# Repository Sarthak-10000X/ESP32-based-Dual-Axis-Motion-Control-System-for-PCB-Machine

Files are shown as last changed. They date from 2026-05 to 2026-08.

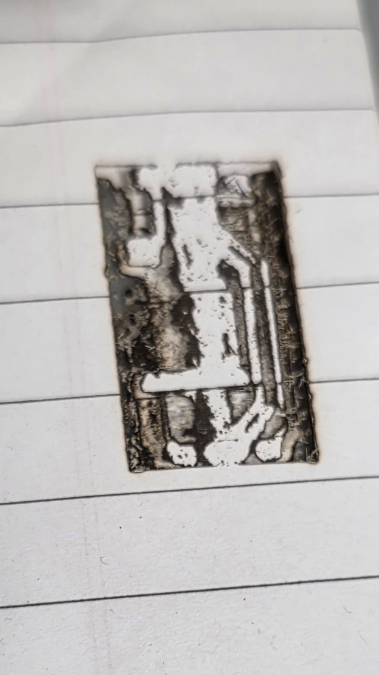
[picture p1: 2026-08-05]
Images-Prototyping/paper trial to test calibration.jpeg

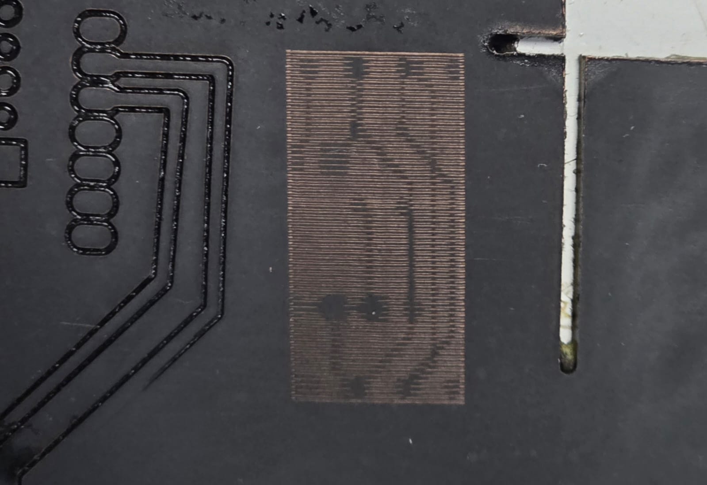
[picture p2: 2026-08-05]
Images-Prototyping/Changed grayscale. Issue remains.jpeg

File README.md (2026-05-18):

# ESP32-based-Dual-Axis-Motion-Control-System-for-PCB-Machine
This project implements a dual-axis motion control system for a PCB machine using the ESP32 microcontroller and TMC2209 stepper motor drivers. It is designed to deliver smooth, precise and low-noise motion through advanced micro-stepping making it suitable for PCB plotting or light CNC applications.

I have choosen the TMC2209 Stepper motor driver because it provides smooth and silent operations using microstepping. It is a 2 phase stepper motor upto 2.8A peak current, 2A RMS. STEP/DIR Interface with 8,16,32 or 64 microstep pin setting. StealthMode2 that is Silent Motor Operation and Smooth Running 256 Microsteps by MicroPlayer interpolation. Additionally, it's UART Interface allows advanced control and tuning making it more suitable for traditional stepper drivers like A4988 or DRV8825.

Heat dissipation is handled using heatsink on the TMC2209 drivers. Each TMC2209 can be equipped with a small aluminum heatsink to dissipate heat generated during operation. Motor current can be properly set via UART to prevent overheating at the source. Use of large copper area helps to spread heat away from the driver.
Power routing is designed with seperate motor, where a 24V supplies the motor drivers and a buck converter provides 5V for the ESP32 and logic pins. Bulk Capacitor are placed across Vm and GND to absorb volatge spikes, while ceramic capacitors ensure stable and high frequency logic voltage. Common grounding used to ensure system stability.

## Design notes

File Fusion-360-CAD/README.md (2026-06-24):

# CAD Practice Models

## Overview

This directory contains CAD models created as part of the learning and skill-development process in Fusion 360. The purpose of these models was to gain hands-on experience with sketching, extrusion, revolves, assemblies, and basic mechanical design principles.

## Software Used

- Fusion 360

## Learning Outcomes

Through the development of these models, the following skills were practiced:

- 2D sketching and dimensioning
- 3D feature creation
- Component-based design
- Assembly fundamentals
- CAD workflow and model organization

## Future Improvements

- Create more complex mechanical assemblies
- Perform motion and interference analysis
- Design project-specific components for the PCB prototyping machine
- Improve design documentation and manufacturing readiness
  
These models were developed for educational and skill-development purposes as part of the PCB Prototyping Machine project.

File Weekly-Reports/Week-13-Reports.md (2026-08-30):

## Week 13 Progress Report: Custom CNC Control Board Development

# Overview:

-Focused on developing the custom control board for the CNC machine.
-Reviewed and updated the circuit schematic based on the required voltage levels, components, protection, and control interfaces.
-Finalized the initial Bill of Materials (BOM) and component footprints for PCB design.

# Tasks Completed:

-Prepared the Bill of Materials (BOM) for the custom CNC control board.
-Assigned appropriate PCB footprints to the selected components.
-Reviewed the power architecture, including 12V input and 5V regulation.
-Evaluated components such as the ATmega328P, LM358, AMS1117, TMC2209, MOSFETs, TVS/flyback protection, and connectors.
-Planned I²C header pins, ISP connector, serial interface, limit-switch connections, and control outputs.
-Added provisions for microstepping selection and future hardware flexibility.
-Reviewed protection requirements for the pump and other inductive loads, including flyback diode and fuse connections.

# Challenges Faced:

-Finalizing the correct components and footprints for reliable PCB implementation.
-Verifying the ATmega328P pin assignments and additional GPIO requirements.
-Determining suitable PWM/control pins for the laser, pump, servo, and safety functions.
-Ensuring adequate protection against voltage spikes, current overload, and inductive switching.

# Key Outcomes:

-Established the initial custom CNC control-board architecture.
-Completed the BOM and PCB footprint assignment for the selected components.
-Identified key hardware requirements for motor control, laser control, pump operation, safety interlocks, and sensors.
-Improved the schematic based on the requirements identified during prototype testing.
-Prepared the design for the next stage of PCB layout and hardware implementation.

# Next Steps:

-Finalize and verify the complete schematic and component selection.

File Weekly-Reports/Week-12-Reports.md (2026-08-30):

# Week 12 Progress Report: Prototype Completion & System Integration

## Overview

- Focused on completing the first functional CNC prototype by integrating the servo-based etching mechanism with the existing CNC system.
- Explored multiple hardware and firmware approaches for controlling the servo motor.
- Successfully integrated and tested the laser, pump, and servo system to validate the complete CNC operation.

## Tasks Completed

- Tested multiple servo-control and wiring configurations.
- Investigated LaserGRBL/GRBL firmware modifications for additional PWM-based control.
- Integrated the etching pump and servo mechanism with the CNC system.
- Performed complete system testing to verify coordinated operation of the major CNC components.

## Challenges Faced

- Difficulty identifying a suitable PWM-capable output for direct servo control within the existing CNC controller configuration.
- Required evaluation of multiple hardware components and circuit configurations to achieve reliable operation.
- Existing Arduino UNO + CNC Shield V3 architecture provided limited outputs for additional peripherals.

## Key Outcomes

- Successfully completed the first functional CNC prototype.
- Verified the operation of the laser, stepper motors, pump, and servo mechanism.
- Tested and evaluated multiple hardware and firmware approaches for peripheral control.
- Established a working prototype that can serve as the foundation for the next-generation CNC control board.

## Next Steps

- Design and develop a custom CNC control PCB integrating the required motion, laser, pump, and servo-control circuitry.
- Study the STM32 microcontroller platform for improved PWM, GPIO, motion-control, and peripheral capabilities.
- Evaluate STM32 as a potential replacement for the Arduino UNO-based control architecture.
- Begin planning the circuit architecture and pin mapping for the custom CNC controller.

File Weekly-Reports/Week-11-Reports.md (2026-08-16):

## Week 11 Progress Report: Firmware Evaluation & PWM Signal Analysis

# Overview

- Focused on evaluating and modifying the LaserGRBL control system to support an additional PWM-controlled output.
- Investigated available PWM signals on the Arduino UNO with CNC Shield V3 using an oscilloscope.
- Tested different spray-paint coatings to determine their suitability for laser engraving PCB traces.
- Troubleshot and resolved a low-laser-power issue observed during engraving.

# Tasks Completed

- Checked PWM outputs from different pins available on the CNC Shield V3.
- Used an oscilloscope to verify PWM signal generation and behavior.
- Investigated the possibility of assigning an additional PWM output for pump-speed control.
- Resolved the previously observed low laser-power problem and verified improved laser operation.
- Tested engraving quality and examined the resulting trace patterns.
- Evaluated different spray-paint coatings for improved laser engraving performance.

# Challenges Faced

- No suitable additional PWM output was identified apart from the Z-axis-related output available on the CNC Shield V3.
- Firmware modification was limited by the available hardware pin configuration.
- The A0 pin, although available on the Arduino UNO, is configured as an analog input and required additional firmware/hardware consideration before being used for PWM control.
- Integrating an additional independently controlled PWM output without affecting existing CNC functions remains a challenge.

# Key Outcomes

- Successfully verified PWM signals from the CNC Shield V3 using an oscilloscope.
- Improved understanding of GRBL PWM generation and Arduino pin mapping.
- Resolved the laser low-power issue and achieved more consistent laser output.
- Successfully evaluated engraving traces and laser power during testing.
- Identified the limitations of the current Arduino UNO + CNC Shield V3 architecture for additional PWM control.
- Narrowed down the requirements for a future controller upgrade.

# Next Steps

- Test double-layer spray-paint coating for improved PCB trace engraving.
- Optimize laser power, speed, and number of passes for clean trace formation.
- Continue investigating firmware-based additional PWM control.
- If the current GRBL/UNO architecture cannot provide the required functionality, evaluate STM32 as a potential CNC controller for expanded PWM, I/O, and motion-control capabilities.

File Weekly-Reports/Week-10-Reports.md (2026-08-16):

# Week 10 Progress Report: Etching System Integration & Firmware Exploration

## Overview

- Focused on integrating the etching system with the CNC machine.
- Connected a coolant pump for PCB etching using an N-channel MOSFET for electronic ON/OFF control.
- Continued PCB engraving tests using different passes and engraving parameters.
- Studied the GRBL firmware architecture and source code to explore additional PWM control options.

## Tasks Completed

- Integrated the etching pump with the CNC system using an N-channel MOSFET.
- Tested pump speed variation by manually adjusting the voltage regulator.
- Engraved additional PCB samples using different numbers of passes and machine parameters.
- Studied GRBL firmware and its PWM/spindle control implementation.
- Investigated the possibility of using an available Arduino PWM pin for independent pump-speed control.

## Challenges Faced

- Pump-speed adjustment through the voltage regulator is manual and not easily repeatable.
- The Arduino UNO with CNC Shield V3 provides limited dedicated PWM functionality, with the existing spindle/laser PWM output already being utilized.
- Additional firmware and hardware modifications are required to achieve computer-controlled variable pump speed.

## Key Outcomes

- Successfully integrated the pump into the PCB etching system.
- Established MOSFET-based electronic control for the pump.
- Evaluated different engraving passes and parameters for improved PCB fabrication.
- Developed a better understanding of GRBL firmware and PWM control.
- Identified a potential approach for adding independent computer-controlled pump-speed control using an available PWM pin.

## Next Steps

- Implement software-controlled pump speed instead of manual voltage adjustment.
- Modify and test GRBL to support an additional PWM-controlled output.
- Verify reliable synchronization between laser engraving and etching operations.
- Study STM32-based CNC control as a possible future upgrade for improved I/O and control flexibility.

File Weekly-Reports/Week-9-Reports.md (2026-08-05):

# Week 9 Progress Report: Successful Calibration & Engraving Results

## Overview

- Focused on improving the accuracy and consistency of CNC laser engraving.
- Successfully resolved the previously observed double-tracing issue.
- Achieved significantly improved and nearly accurate engraving results after mechanical adjustments.

## Tasks Completed

- Engraved multiple images and achieved near-accurate output.
- Tightened the pulley/belt system to compensate for mechanical looseness and improve motion accuracy.
- Identified and resolved the double-line tracing problem caused by loose pulley tension.
- Performed additional engraving tests to verify the improvement.

## Challenges Faced

- Engraved images were slightly different from the expected output due to grayscale conversion and image processing.
- Loose pulley/belt tension caused mechanical inaccuracies and positioning errors during engraving.

## Key Outcomes

- Successfully eliminated the double-tracing problem.
- Improved CNC motion accuracy through mechanical belt/pulley adjustment.
- Achieved cleaner and more accurate engraved images.
- Established a more reliable mechanical setup for further engraving optimization.

## Next Steps

- Further optimize calibration to achieve clean and precise single-line traces.
- Use the optimized engraving output to create a PCB prototype.
- Test suitable laser-compatible spray paint/coating for PCB fabrication.
- Optimize laser power, speed, and coating parameters for accurate PCB trace engraving.

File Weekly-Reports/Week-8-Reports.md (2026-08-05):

# Week 8 Progress Report: CNC Laser Engraving Calibration

## Overview

- Focused on calibrating the CNC laser engraving system for better accuracy and consistent engraving quality.
- Conducted multiple engraving tests to identify and troubleshoot double-line tracing.
- Tested different engraving speeds and calibration parameters.

## Tasks Completed

- Performed multiple CNC calibration and engraving tests.
- Engraved images and test patterns using different speed settings.
- Evaluated line accuracy, spacing, image quality, and motion consistency.
- Compared engraving results under different calibration conditions.

## Challenges Faced

- Double/duplicate engraving lines appeared consistently during testing.
- Changing engraving speeds did not significantly improve the issue.
- Further investigation is required into steps/mm, mechanical backlash, belt tension, microstepping, acceleration, laser timing, and G-code/toolpath generation.

## Key Outcomes

- Established a baseline for CNC engraving performance.
- Confirmed that the double-line issue is repeatable and requires further troubleshooting.
- Identified key parameters that need to be tested for further optimization.

## Next Steps

- Identify and eliminate the cause of double-line tracing.
- Verify X/Y steps-per-mm and mechanical alignment.
- Check belt tension, backlash, and microstepping.
- Inspect G-code/toolpaths for duplicate paths.
- Optimize engraving speed, laser power, and image resolution.
- Produce a clean and accurate reference engraving.

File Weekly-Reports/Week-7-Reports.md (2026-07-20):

# Week 7 Progress Report: Motion Optimization and Engraving Accuracy

## Overview

Week 7 was dedicated to optimizing the performance of the PCB prototyping machine by studying the relationship between motor speed, travel resolution, and laser power. Multiple machine configurations were evaluated to improve engraving quality while maintaining stable motion. Research was also conducted on integrating a display interface into the next version of the machine.

## Tasks Completed

- Investigated the effects of motor speed, travel resolution, and laser power on engraving performance.
- Performed multiple configuration and calibration tests to optimize motor speed.
- Successfully generated more accurate engraved images compared to previous iterations.
- Evaluated different machine parameters, including feed rate and travel resolution, to improve motion accuracy.

## Challenges Faced

- Machine speed remained significantly lower than the desired operating range when compared with similar CNC and 3D printer systems.
- Increasing the maximum feed rate caused the stepper motors to skip steps, resulting in positioning errors.
- Balancing engraving accuracy with higher machine speeds required further optimization and calibration.

## Key Outcomes

- Improved engraving accuracy through systematic parameter tuning.
- Gained a deeper understanding of the relationship between feed rate, travel resolution, and laser power.
- Identified the practical limits of the current motion control setup for future hardware and firmware improvements.

## Next Steps

- Further optimize motion parameters to increase machine speed without compromising accuracy.
- Achieve reliable and accurate image engraving for complex patterns.
- Begin integrating the display module into the CNC machine for improved user interaction and system monitoring.

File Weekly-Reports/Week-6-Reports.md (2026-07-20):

# Week 6 Progress Report: Machine Optimization and Prototype Fabrication

## Overview

-Week 6 focused on improving the performance of the PCB prototyping machine through motion parameter optimization and mechanical fabrication. Extensive testing was carried out to increase machine speed while maintaining engraving accuracy. The soldering iron PCB was successfully fabricated, and the base plate for the next-generation CNC prototype was manufactured using a metal cutting machine. Alongside hardware development, CAD skills were further enhanced through Fusion 360 modeling exercises.

## Tasks Completed

- Investigated and optimized machine speed and laser power parameters for improved CNC performance.
- Successfully fabricated the soldering iron PCB for hardware validation.
- Learned the safe operation of the metal cutting machine, including accurate straight and angled cuts.
- Created a robotic arm model in Fusion 360 to further develop CAD design skills.
- Integrated and tested updated speed parameters within the CNC control system.

## Challenges Faced

- Despite multiple configuration changes, the machine speed remained lower than the desired operating range.
- Increasing the motion speed affected dimensional accuracy, resulting in slightly enlarged engraved geometries.
- Maintaining an optimal balance between speed, positioning accuracy, and engraving quality required additional calibration and testing.

## Key Outcomes

- Successfully fabricated the base structure for the next-generation CNC machine.
- Improved understanding of machine parameter tuning and motion optimization.
- Enhanced practical manufacturing skills through metal cutting operations.
- Continued strengthening CAD design proficiency by developing a robotic arm model in Fusion 360.

## Next Steps

- Further optimize machine speed while preserving dimensional accuracy.
- Continue mechanical assembly of the new CNC machine prototype.
- Improve engraving precision for accurate image and PCB trace generation.
- Validate the performance of the newly fabricated machine through comprehensive testing.

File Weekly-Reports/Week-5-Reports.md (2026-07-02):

# Week 5 Progress Report: Homing System Integration and Prototype Development

## Overview

Week 5 focused on achieving reliable machine homing, improving system stability, and initiating the first version of the PCB prototyping machine. Persistent limit switch issues were resolved, enabling successful homing using the GRBL firmware. In parallel, a standard PCB schematic for the soldering iron was designed to streamline the assembly process, and the software developed by the software team was validated on the Arduino-based setup.

## Tasks Completed

- Resolved limit switch issues affecting machine operation.
- Successfully implemented and validated the homing cycle with the home position configured at the front-right corner.
- Designed a standardized PCB schematic for the soldering iron to improve manufacturing consistency.
- Created a 3D CAD model of a servo motor in Fusion 360.

## Challenges Faced

- Hard limit alarms were triggered during laser operation due to electrical noise affecting the limit switch signals.
- Homing repeatedly failed during testing and required firmware configuration and troubleshooting within GRBL.
- Encountered connectivity issues while designing the soldering iron PCB schematic, requiring circuit verification and corrections.

## Key Outcomes

- Achieved reliable homing functionality for the CNC machine.
- Improved overall machine stability by resolving limit switch-related issues.
- Standardized the soldering iron PCB design for future production.
- Continued strengthening CAD modeling skills through component design in Fusion 360.

## Next Steps

- Integrate a display interface into the CNC machine for improved user interaction.
- Develop the complete CAD model for the first functional prototype of the PCB prototyping machine.
- Design and manufacture a dedicated PCB for the soldering iron.

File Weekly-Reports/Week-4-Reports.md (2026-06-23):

# Week 4 Progress Report: Motion Control Optimization and CAD Learning

## Overview

-Week 4 focused on improving machine motion control, refining the control circuitry, and investigating image generation accuracy. Modifications were made to the existing schematic to improve signal integrity, resulting in better Y-axis motor performance. In parallel, learning and practicing CAD design using Fusion 360 was initiated to support future mechanical development activities.

## Tasks Completed

- Updated and optimized the control schematic for improved system reliability.
- Added a 1 kΩ resistor to the Y-axis STEP/DIR signal lines to improve signal stability and reduce motor oscillation.
- Tested the machine control software and laser module developed by the software team.
- Successfully generated and engraved basic geometric shapes using the laser module.
- Performed step-by-step motor calibration to improve positional accuracy.
- Migrated testing from the ESP32 setup to an Arduino and CNC Shield configuration for comparative evaluation.
- Designed a bottle model and a robotic gripper in Fusion 360 as part of CAD learning and practice.
- Assembled and tested twelve soldering iron units.

## Challenges Faced

- Resolved the Y-axis oscillation issue; however, motor speed and performance required further optimization.
- Observed elongated and distorted engraved images during laser testing.
- Identified positional differences between G-code generated by the software team and LaserGRBL.
- Fine PCB traces were not reproduced accurately during the engraving process, resulting in missing features.

## Key Outcomes

- Improved Y-axis motion stability through circuit-level modifications.
- Achieved successful laser engraving of basic test patterns.
- Enhanced machine calibration accuracy and gained practical experience with CNC-based control systems.
- Developed foundational CAD modeling skills using Fusion 360.

## Next Steps

- Improve image processing and engraving accuracy using the Arduino and CNC Shield setup.
- Implement and validate homing functionality within the CNC control system.
- Continue developing CAD modeling proficiency in Fusion 360.
- Investigate and resolve image scaling and trace reproduction issues.

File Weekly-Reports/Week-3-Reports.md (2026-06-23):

# Week 3 Progress Report: Motion Control and Software Integration

## Overview

-Week 3 focused on troubleshooting the Y-axis motion control system, integrating safety mechanisms, and testing software-based machine operation. Limit switch functionality was implemented for the X-axis, and motor control was verified using LaserGRBL. Initial laser module testing and system-level debugging activities were also carried out.

## Tasks Completed

- Integrated and tested an X-axis limit switch for homing and boundary protection.
- Performed initial testing of the laser module and laser driver.
- Investigated and tested multiple approaches to resolve Y-axis motor issues.
- Successfully controlled and jogged the X-axis motor using LaserGRBL.
- Assembled and tested eight soldering iron units for delivery.

## Challenges Faced

- The Y-axis stepper motor exhibited low-speed operation, oscillation, and unstable movement under continuous command inputs.
- Homing offset parameters were not functioning as expected, causing the limit switch to remain engaged and requiring system resets.
- Additional debugging was required to achieve reliable and repeatable machine motion.

## Key Outcomes

- Established software-based motor control through LaserGRBL.
- Implemented a functional limit switch mechanism for machine safety.
- Improved understanding of machine homing, motion control, and troubleshooting procedures.

## Next Steps

- Resolve Y-axis motor performance and stability issues.
- Optimize homing and limit switch behavior for reliable operation.
- Generate and engrave test images using LaserGRBL.
- Validate overall machine accuracy and repeatability.

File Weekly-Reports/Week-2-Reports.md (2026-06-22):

# Week 2 Progress Report: Firmware Implementation and Hardware Testing

## Overview

Week 2 focused on firmware implementationamd hardware prototyping. An initial breadboard prototype consisting of an ESP32 controller and TMC2209 stepper motor drivers was developed. Additionally, FluidNC firmware was studied and configured to establish motion control for the PCB prototyping machine. Practical exposure to soldering iron circuitry and assembly was also gained during this period.

## Tasks Completed

- Developed and tested a breadboard prototype using ESP32 and TMC2209 drivers.
- Studied the configuration of FluidNC firmware.
- Successfully controlled and moved a stepper motor using FluidNC.
- Tested the motor control software developed by the software team.
- Assembled and tested six soldering iron units.
- Learned the working principles and circuitry of soldering irons.

## Challenges Faced

- Observed oscillation and vibration issues in the Y-axis stepper motor.
- Attempted multiple troubleshooting methods, including motor wire reconfiguration and driver testing, but the issue persisted.
- Soldering iron assembly required significant time and careful handling during manufacturing and testing.

## Key Outcomes

- Established a functional firmware-based motion control setup.
- Verified communication between hardware and control software.
- Improved understanding of embedded motion control systems and hardware assembly processes.

## Next Steps

- Continue troubleshooting and resolving the Y-axis motor vibration issue.
- Integrate and test the laser module with the existing control system.
- Further optimize FluidNC configuration for stable machine operation.

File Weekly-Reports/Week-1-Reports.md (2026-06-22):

# Week 1 Progress Report: Project Initiation and Requirement Analysis

## Overview

The first week focused on understanding the PCB prototyping workflow, evaluating existing PCB fabrication methods. Initial efforts were directed toward hands-on PCB fabrication, component identification, and familiarization with the technologies required for the project.

## Activities Performed

1. Manual PCB Fabrication Study

- Fabricated a PCB using the toner transfer (iron heat transfer) method on a copper-clad board.
- Studied the complete workflow involved in conventional DIY PCB manufacturing.
- Analyzed the limitations of manual PCB fabrication techniques.

2. Prototype Circuit Development

- Printed (Ink jet printer) the circuit schematic for a clap-switch application.
- Identified and documented all required electronic components.

3. Technology Research

- Conducted preliminary research on PCB prototyping machines and CNC-based fabrication systems.
- Studied the fundamentals of motion control systems, and PCB engraving processes.
- Explored the role of firmware and controller software used in automated PCB manufacturing systems.

## Key Observations

- The toner transfer method produced inconsistent and extremely thin PCB traces, leading to poor electrical connectivity in several regions.
- Manual PCB fabrication required significant processing time and multiple iterations to achieve acceptable results.
- Trace quality and repeatability were identified as major limitations of the conventional DIY fabrication approach.

## Challenges Encountered

- Difficulty in achieving reliable and uniform PCB trace transfer onto the copper surface.
- Incomplete trace formation resulted in connectivity issues during circuit implementation.
- The overall fabrication process was time-consuming and highly dependent on manual precision.

## Outcomes

- Successfully developed an understanding of the PCB fabrication workflow.
- Completed component identification and circuit prototyping activities.
- Established the technical motivation for developing an automated PCB prototyping machine.

## Next Steps
- Begin the study and implementation of FluidNC firmware for machine control.
- Investigate motion control hardware requirements for the PCB prototyping machine.

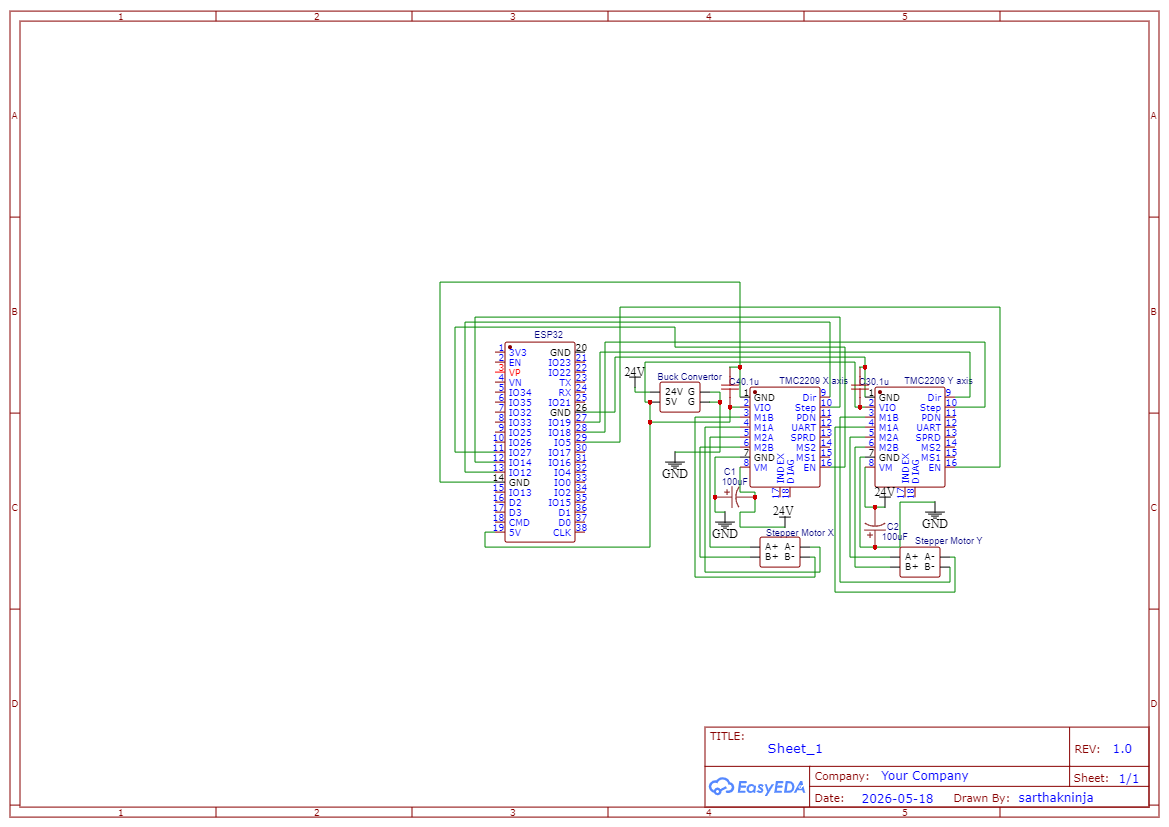
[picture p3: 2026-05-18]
Schematic_Schematic-Diagram-for-Motion-Control-System_2026-05-18.png

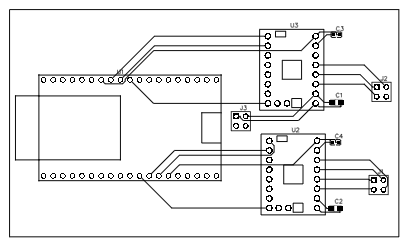
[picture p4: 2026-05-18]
PCB_PCB_Schematic-Diagram-for-Motion-Control-System_2026-05-18.png

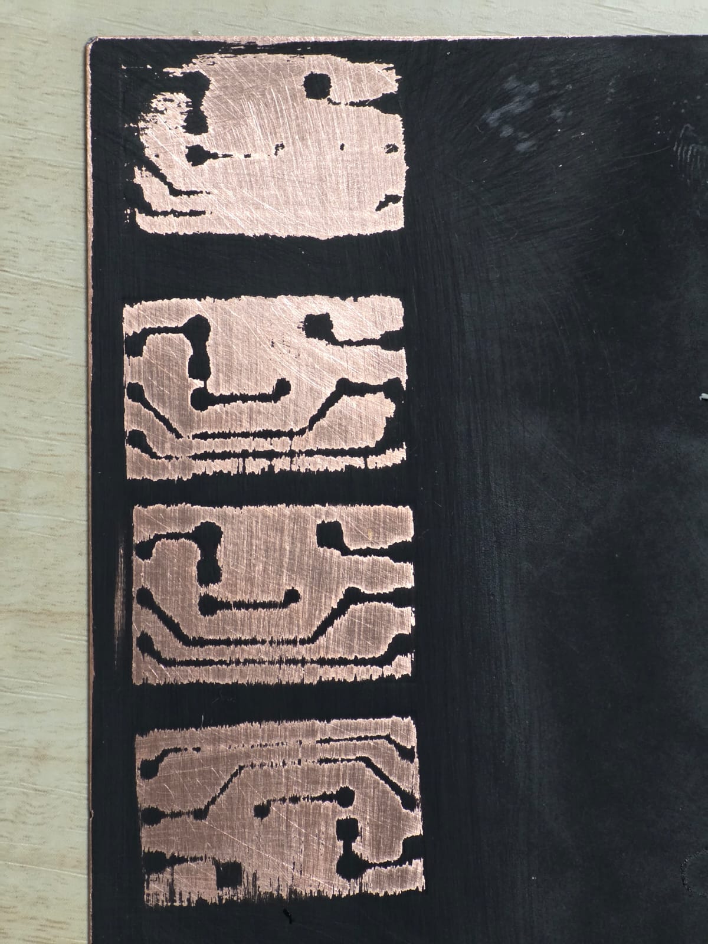
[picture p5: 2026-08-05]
Images-Prototyping/Polished tracing lines.jpeg

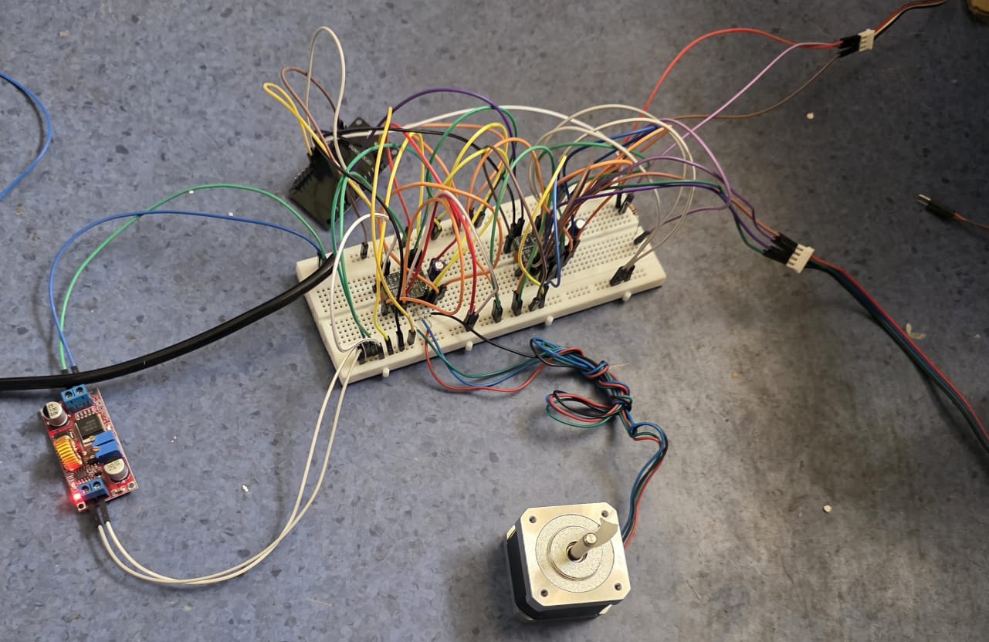
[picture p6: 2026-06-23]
Images-Prototyping/Circuit View(BreadBoard Protoype).jpeg

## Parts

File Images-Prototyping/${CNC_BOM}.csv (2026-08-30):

Reference | Qty | Value | DNP | Exclude from BOM | Exclude from Board | Footprint | Datasheet | Description
C1,C2 | 2 | 22pF |  |  |  | Capacitor_THT:C_Disc_D3.0mm_W2.0mm_P2.50mm |  | Unpolarized capacitor
C3,C4,C5,C6,C7 | 5 | 100nF |  |  |  | Capacitor_THT:C_Disc_D3.0mm_W2.0mm_P2.50mm |  | Unpolarized capacitor
C8,C9,C10,C11 | 4 | 100uF |  |  |  | Capacitor_THT:CP_Radial_D8.0mm_P3.50mm |  | Polarized capacitor
C12 | 1 | C_Polarized |  |  |  | Capacitor_THT:CP_Radial_D10.0mm_P3.50mm |  | Polarized capacitor
D1 | 1 | D_Schottky |  |  |  | Diode_THT:D_DO-201AD_P15.24mm_Horizontal |  | Schottky diode
F1 | 1 | Fuse |  |  |  | Fuse:Fuse_1812_4532Metric |  | Fuse
J1 | 1 | X_limitswitch |  |  |  | Connector_PinHeader_2.54mm:PinHeader_1x02_P2.54mm_Vertical |  | Generic connector, single row, 01x02, script generated
J2 | 1 | Y_limitswitch |  |  |  | Connector_PinHeader_2.54mm:PinHeader_1x02_P2.54mm_Vertical |  | Generic connector, single row, 01x02, script generated
J3 | 1 | X_nema17 |  |  |  | Connector_PinHeader_2.54mm:PinHeader_1x02_P2.54mm_Vertical |  | Generic connector, single row, 01x04, script generated
J4 | 1 | Y_nema17 |  |  |  | Connector_PinHeader_2.54mm:PinHeader_1x02_P2.54mm_Vertical |  | Generic connector, single row, 01x04, script generated
J5 | 1 | Z_nema17 |  |  |  | Connector_PinHeader_2.54mm:PinHeader_1x02_P2.54mm_Vertical |  | Generic connector, single row, 01x04, script generated
J6 | 1 | Z_limitswitch |  |  |  | Connector_PinHeader_2.54mm:PinHeader_1x02_P2.54mm_Vertical |  | Generic connector, single row, 01x02, script generated
J7 | 1 | Laser |  |  |  | Connector_PinHeader_2.54mm:PinHeader_1x03_P2.54mm_Vertical |  | Generic connector, single row, 01x03, script generated
J8 | 1 | Pump |  |  |  | Connector_PinHeader_2.54mm:PinHeader_1x02_P2.54mm_Vertical |  | Generic connector, single row, 01x02, script generated
J9 | 1 | X_tmc2209 |  |  |  | Connector_PinHeader_2.54mm:PinHeader_2x08_P2.54mm_Vertical |  | Generic connector, double row, 02x07, odd/even pin numbering scheme (row 1 odd numbers, row 2 even numbers), script generated (kicad-library-utils/schlib/autogen/connector/)
J10 | 1 | Y_tmc2209 |  |  |  | Connector_PinHeader_2.54mm:PinHeader_2x08_P2.54mm_Vertical |  | Generic connector, double row, 02x07, odd/even pin numbering scheme (row 1 odd numbers, row 2 even numbers), script generated (kicad-library-utils/schlib/autogen/connector/)
J11 | 1 | Z_tmc2209 |  |  |  | Connector_PinHeader_2.54mm:PinHeader_2x08_P2.54mm_Vertical |  | Generic connector, double row, 02x07, odd/even pin numbering scheme (row 1 odd numbers, row 2 even numbers), script generated (kicad-library-utils/schlib/autogen/connector/)
J12 | 1 | ISP |  |  |  | Connector_PinHeader_2.54mm:PinHeader_2x03_P2.54mm_Vertical |  | Generic connector, double row, 02x03, odd/even pin numbering scheme (row 1 odd numbers, row 2 even numbers), script generated (kicad-library-utils/schlib/autogen/connector/)
J13 | 1 | USB_C_Receptacle_USB2.0_16P |  |  |  | Connector_USB:USB_C_Receptacle_HRO_TYPE-C-31-M-12 | https://www.usb.org/sites/default/files/documents/usb_type-c.zip | USB 2.0-only 16P Type-C Receptacle connector
J14 | 1 | XL4015_IN |  |  |  | Connector_PinHeader_2.54mm:PinHeader_1x02_P2.54mm_Vertical |  | Generic connector, single row, 01x02, script generated
J15 | 1 | XL4015_OUT |  |  |  | Connector_PinHeader_2.54mm:PinHeader_1x02_P2.54mm_Vertical |  | Generic connector, single row, 01x02, script generated
Q1 | 1 | IRLZ44N |  |  |  | Package_TO_SOT_THT:TO-220-3_Vertical | http://www.irf.com/product-info/datasheets/data/irlz44n.pdf | 47A Id, 55V Vds, 22mOhm Rds Single N-Channel HEXFET Power MOSFET, TO-220AB
R1,R2,R3 | 3 | 10k |  |  |  | Resistor_SMD:R_0603_1608Metric |  | Resistor, US symbol
R4,R5 | 2 | 5.1k |  |  |  | Resistor_SMD:R_0603_1608Metric |  | Resistor, US symbol
U1 | 1 | ATmega328-P |  |  |  | Package_DIP:DIP-28_W7.62mm | http://ww1.microchip.com/downloads/en/DeviceDoc/ATmega328_P%20AVR%20MCU%20with%20picoPower%20Technology%20Data%20Sheet%2040001984A.pdf | 20MHz, 32kB Flash, 2kB SRAM, 1kB EEPROM, DIP-28
U2 | 1 | CH340C |  |  |  | Package_SO:SOIC-16_3.9x9.9mm_P1.27mm | https://datasheet.lcsc.com/szlcsc/Jiangsu-Qin-Heng-CH340C_C84681.pdf | USB serial converter, crystal-less, UART, SOIC-16
Y1 | 1 | Crystal |  |  |  | Crystal:Crystal_HC49-4H_Vertical |  | Two pin crystal
Material To Scrap or get from other source
U2 | 1 | CH340C |  |  |  | Package_SO:SOIC-16_3.9x9.9mm_P1.27mm | https://datasheet.lcsc.com/szlcsc/Jiangsu-Qin-Heng-CH340C_C84681.pdf | USB serial converter, crystal-less, UART, SOIC-16
TVS diode 1
C8,C9,C10,C11 | 4 | 100uF |  |  |  | Capacitor_THT:CP_Radial_D8.0mm_P3.50mm |  | Polarized capacitor
Connector_PinHeader_2.54mm:PinHeader_1x02_P2.54mm_Vertical |  | Generic connector, single row, 01x02, script generated
Connector_PinHeader_2.54mm:PinHeader_1x02_P2.54mm_Vertical |  | Generic connector, single row, 01x02, script generated
Connector_PinHeader_2.54mm:PinHeader_1x02_P2.54mm_Vertical |  | Generic connector, single row, 01x04, script generated
Connector_PinHeader_2.54mm:PinHeader_1x02_P2.54mm_Vertical |  | Generic connector, single row, 01x04, script generated
Connector_PinHeader_2.54mm:PinHeader_1x02_P2.54mm_Vertical |  | Generic connector, single row, 01x04, script generated
Connector_PinHeader_2.54mm:PinHeader_1x02_P2.54mm_Vertical |  | Generic connector, single row, 01x02, script generated
Connector_PinHeader_2.54mm:PinHeader_1x03_P2.54mm_Vertical |  | Generic connector, single row, 01x03, script generated
Connector_PinHeader_2.54mm:PinHeader_1x02_P2.54mm_Vertical |  | Generic connector, single row, 01x02, script generated
Connector_PinHeader_2.54mm:PinHeader_2x08_P2.54mm_Vertical |  | Generic connector, double row, 02x07, odd/even pin numbering scheme (row 1 odd numbers, row 2 even numbers), script generated (kicad-library-utils/schlib/autogen/connector/)
Connector_PinHeader_2.54mm:PinHeader_2x08_P2.54mm_Vertical |  | Generic connector, double row, 02x07, odd/even pin numbering scheme (row 1 odd numbers, row 2 even numbers), script generated (kicad-library-utils/schlib/autogen/connector/)
Connector_PinHeader_2.54mm:PinHeader_2x08_P2.54mm_Vertical |  | Generic connector, double row, 02x07, odd/even pin numbering scheme (row 1 odd numbers, row 2 even numbers), script generated (kicad-library-utils/schlib/autogen/connector/)
Some of the Connection header pins we can get.
Y1 | 1 | Crystal |  |  |  | Crystal:Crystal_HC49-4H_Vertical |  | Two pin crystal

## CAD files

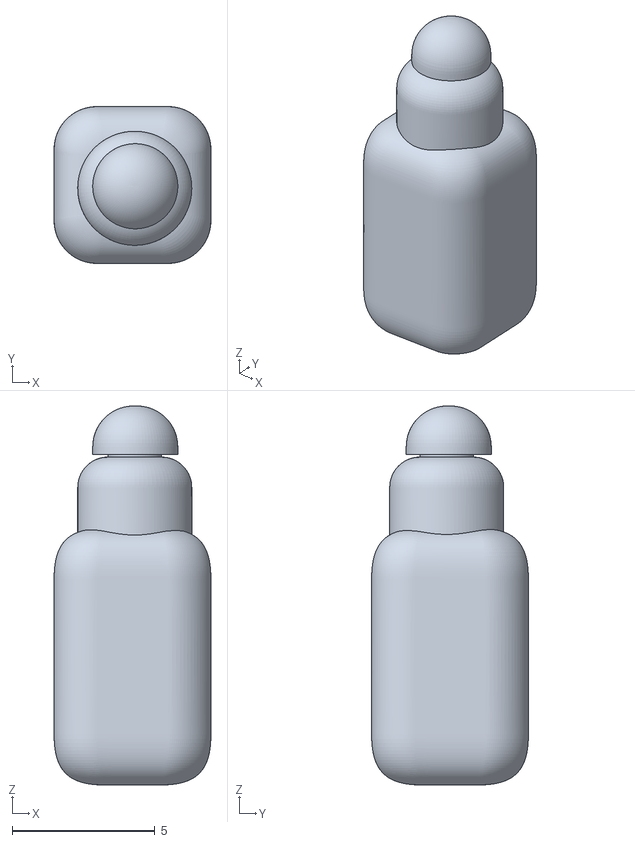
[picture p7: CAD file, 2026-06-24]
Fusion-360-CAD/Bottle Assembly.stl
5.50 x 5.50 x 13.3

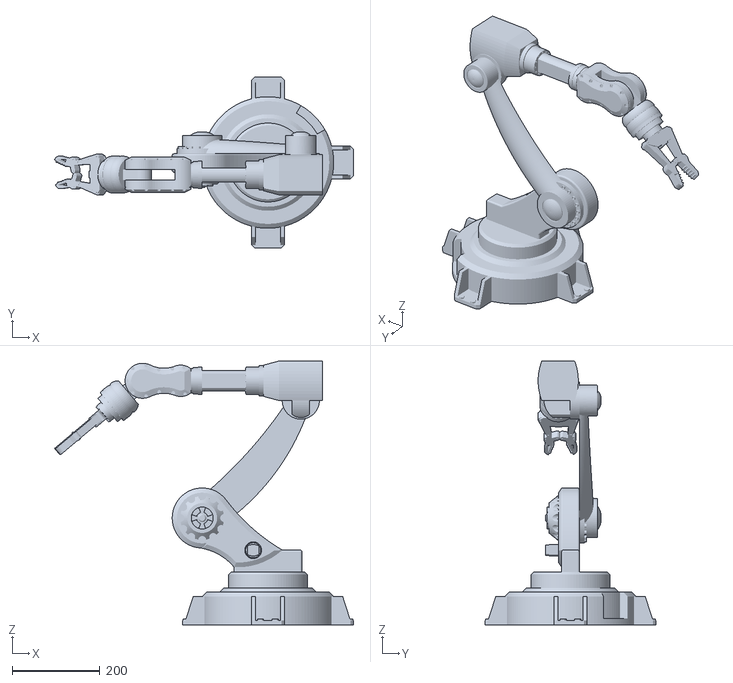
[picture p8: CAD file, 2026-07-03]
Fusion-360-CAD/Robotic Arm.stl
682.3 x 390.5 x 602.1

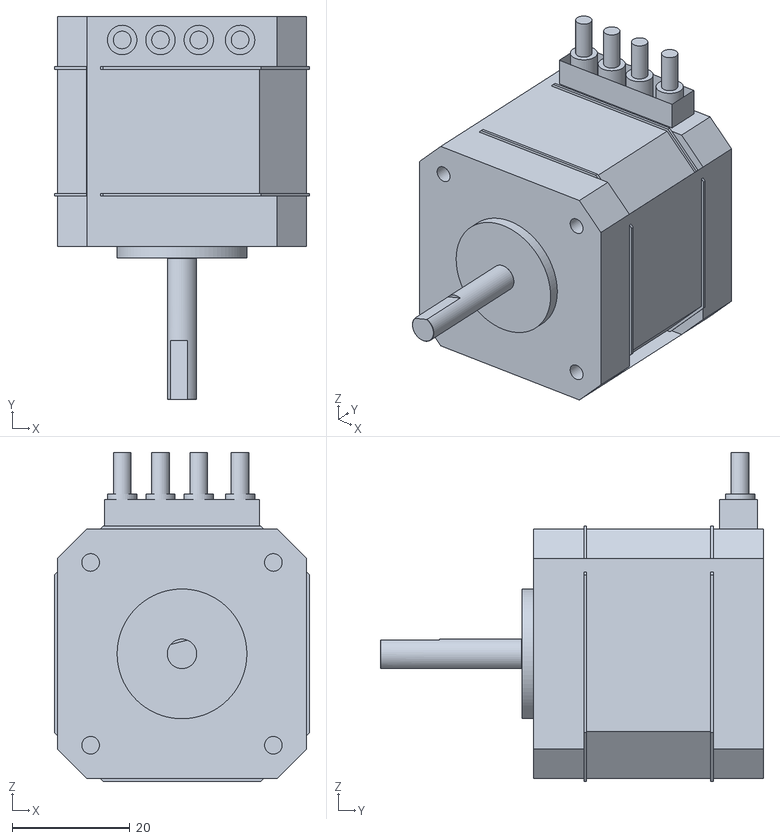
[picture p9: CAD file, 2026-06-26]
Fusion-360-CAD/Stepper Motor.stl
43.3 x 65.0 x 55.8

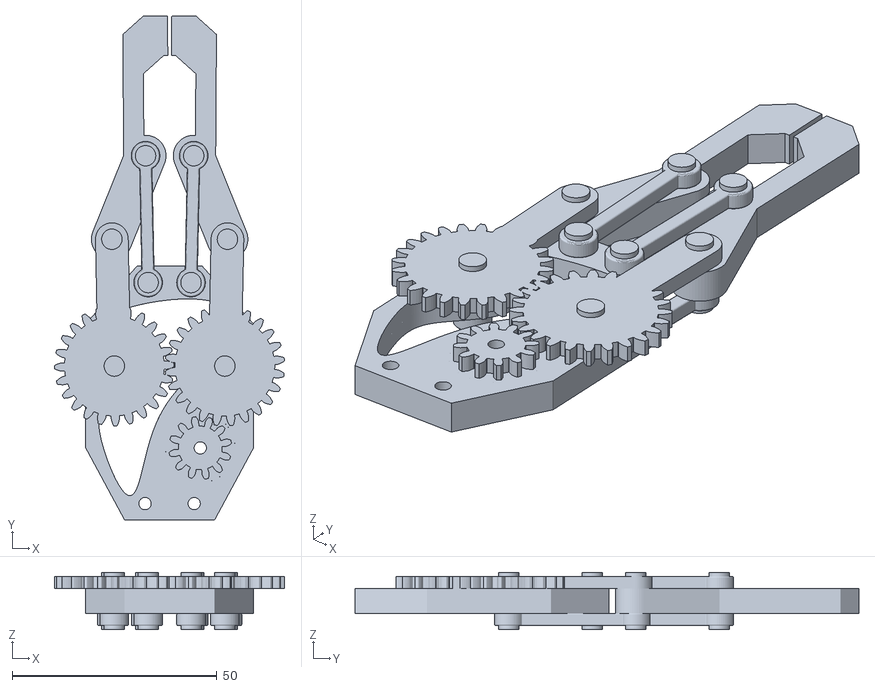
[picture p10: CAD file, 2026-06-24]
Fusion-360-CAD/Robotic Arm Gripper.stl
56.2 x 123.1 x 14.0

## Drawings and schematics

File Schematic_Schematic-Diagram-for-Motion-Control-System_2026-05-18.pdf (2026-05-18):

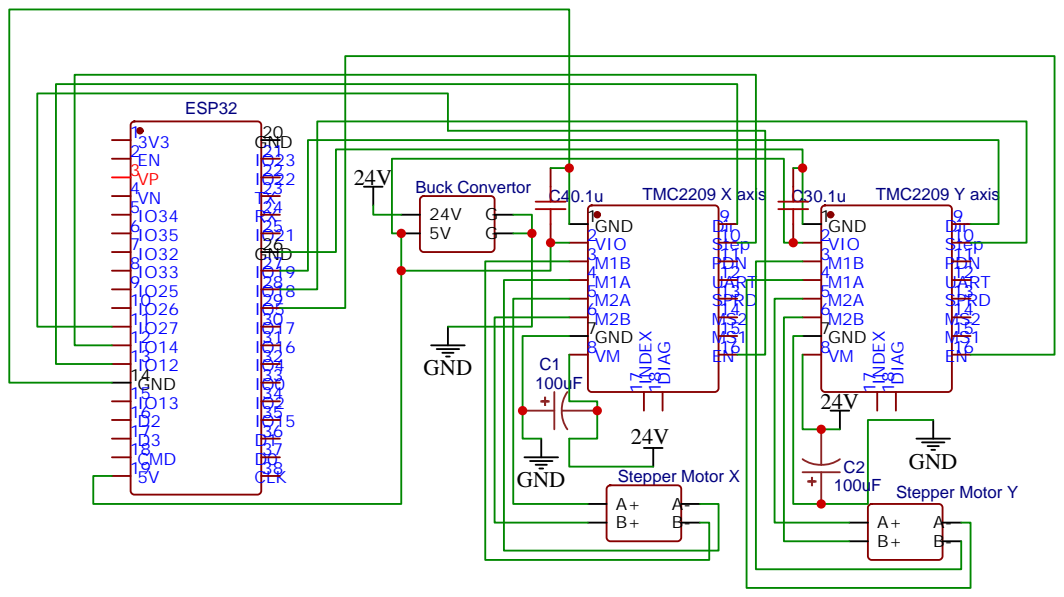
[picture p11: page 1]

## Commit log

2026-05-18 Enhance README with detailed project information
    Expanded project description with details on TMC2209 driver features, heat dissipation, and power routing.
2026-06-19 Week 1 Progress Report on PCB Prototyping
    Documented the activities, observations, challenges, and outcomes from the first week of the project, focusing on PCB prototyping and fabrication techniques.
2026-06-22 Refine next steps in Week 1 report
    Removed redundant next step items and clarified the next steps for the PCB prototyping machine project.
2026-06-23 Week 4 Progress Report
    Documented progress on motion control optimization, CAD learning, and challenges faced during Week 4.
2026-06-24 CAD practice models in Fusion 360
    This README provides an overview of CAD models created for learning purposes in Fusion 360, detailing software used, learning outcomes, and future improvements.
2026-07-02 Week 5 Progress Report on Homing System Integration
    This report summarizes the progress made during Week 5, including tasks completed, challenges faced, key outcomes, and next steps for the project.
2026-07-20 Week 6 progress report on machine optimization
    Documented progress on machine optimization and prototype fabrication, including tasks completed, challenges faced, key outcomes, and next steps.
2026-08-05 Week 8 Progress Report for CNC Calibration
    Documented the progress and challenges faced during CNC laser engraving calibration, including tasks completed and next steps for optimization.
2026-08-16 Week 11 Progress Report on Firmware and PWM Analysis
    Documented progress on firmware evaluation and PWM signal analysis, including tasks completed, challenges faced, key outcomes, and next steps.
2026-08-30 Week 12 Progress Report for CNC Prototype
    Documented the progress made in Week 12, including prototype completion, system integration, challenges faced, and next steps for CNC development.
2026-08-30 Week 13 progress report for CNC control board
    Documented the progress and tasks completed for the custom CNC control board development in Week 13.
